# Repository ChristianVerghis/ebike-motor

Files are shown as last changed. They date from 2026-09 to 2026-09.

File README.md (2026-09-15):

# ebike-motor

**A from-scratch coreless dual-rotor axial-flux rear hub motor for a commuter e-bike, sized analytically and driven by a VESC.**

## What it is

A design-stage hardware project: a DIY coreless dual-rotor axial-flux (YASA-shaped, no iron) rear hub motor, direct drive, 135 mm dropout. Target ~350 W continuous / 750 W peak, ~40 Nm peak at the wheel, 26–27.5" wheel, 48 V, VESC FOC with regen. The stator is 12 epoxy-potted air coils between two 14-pole NdFeB rotors on steel back plates. A 1-D magnetic-circuit sizing script (`sim/sizing.py`) fixed the geometry and winding on 2026-09-01. Phases 0–3 run design, bench spin, wheel integration and a commute log.

Alongside the motor there is research into off-the-shelf conversion kits (`docs/conversion_kits.md`): which one to buy first as a rideable stepping stone and teardown benchmark, and which ones teach anything toward the build.

Everything in the repo is documentation, analysis and one script. Nothing has been machined or wound yet.

## Why I built it

I wanted to understand an electric machine by designing one end to end rather than buying a hub kit: magnet sizing and the air-gap flux budget, winding a coil count and gauge against copper loss and no-load speed, the axial pull between rotors, magnet temperature limits, epoxy glass transition, and how a low-inductance coreless machine behaves under sensorless FOC. Axial flux was chosen because a bicycle wheel is a large-diameter, low-RPM load, which is exactly the regime a pancake motor prefers, and a coreless stator is buildable on a bench with a 3D printer and no laminations.

## Status

As of 2026-09-15:

- Motor spec confirmed 2026-09-01 with `sim/sizing.py`: geometry, magnet size, winding, Kt/Kv, copper loss and rotor pull are pinned (PLAN.md Phase 0). FEMM cross-check still to do.
- Rotor back-plate DXF drawn (`cad/back_plate_3mm_steel.dxf`); no quote requested.
- Conversion-kit research done (`docs/conversion_kits.md`); a stepping-stone direct-drive hub purchase is proposed but undecided.
- BOM, sourcing and a master components list are priced. **No parts have been purchased.** Everything is design-stage.

## Design summary

Phase-1 targets. Numbers are from `sim/sizing.py` (1-D magnetic circuit with empirical leakage, good to roughly 10–15 %); FEMM is meant to refine them.

| Item | Value | Why |
|---|---|---|
| Topology | Dual-rotor, single coreless stator, no iron | No rotor-stator attraction, forgiving gaps, zero cogging, bench-buildable stator |
| Outer diameter | 240 mm | Torque scales with r²; fits inside 27.5" spokes |
| Poles / coils | 14 poles per rotor / 12 coils (LRK-style, wye) | Winding factor 0.933; ~29 Hz electrical at 250 rpm, no litz needed |
| Magnets | 28× N42 1"×1"×3/8" (25.4×25.4×9.5 mm), one per pole, radial at r 92–117 mm | 9.5 mm magnets across a 10 mm stator give ~0.49 T peak; 5 mm magnets only ~0.31 T |
| Rotor back plates | 3 mm mild steel, OD 240 / ID 130 | Flux return; stainless is non-magnetic |
| Stator | 10 mm epoxy/fibreglass potted disc, 2 mm air gap each side | Thinner stator raises gap flux; 2 mm gaps tolerate wobble |
| Winding | 30 turns × 2 strands 14 AWG per coil | Kt ≈ 0.48 Nm/A, ~460 rpm no-load at 42 V |
| Torque | ~29 Nm at 60 A, ~38 Nm at 80 A phase | VESC motor current max set to 80 A for launches |
| Copper loss | ~45 W at 8 Nm cruise, ~160 W at 15 Nm hill | Hill torque is minutes, not continuous; thermal cutback at 85 °C |
| Axial pull | ~0.8 kN between rotors | Carried rotor-to-rotor through OD bolts, not through the stator |
| Axle | 14 mm hub-motor replacement axle, Grin V7 14 mm torque arm | 12 mm hollow axles shear below 80 Nm at the arm |
| Controller | VESC 6-class FOC (Flipsky 75100 Pro candidate), 48 V 13S | Sensorless FOC and regen; low coreless inductance is the known gotcha |
| Core material | None in phase 1; laminated M270-35A segments in phase 2 | Ferrite saturates at ~0.45 T, rejected; rotors fixed so a cored stator drops in later |
| Magnet pattern | Plain alternating N-S; Halbach deferred | ~80 % of Halbach field, none of the orientation fiddliness |
| Mass | ~5 kg motor (1.3 kg magnets) | Coreless penalty, accepted for phase 1 |

## Layout

| Path | Contents |
|---|---|
| `PLAN.md` | Motor phases 0–3, milestones, timeline, risks |
| `GOALS.md` | Working checklist: Phase 0 design steps, bench motor, wheel and ride, north-star goals |
| `BOM.md` | Motor parts list, budget scenarios, what to 3D print and what not to |
| `SOURCING.md` | Priced supplier list per order (Order 0–3) |
| `build_log.md` | Dated log of decisions and research |
| `project.yml` | Project manifest (name, links, checklist sections) |
| `sim/sizing.py` | Analytical sizing: gap flux, Kt/Kv, copper loss, fill, rotor pull; prints a design sweep |
| `cad/` | `back_plate_3mm_steel.dxf` rotor back plate for laser/waterjet cutting, plus notes |
| `docs/design.html` | Motor diagrams: cross-section, coil/pole plan, exploded stack, bike placement, key numbers |
| `docs/roadmap.html` | Phase 0–3 timeline and where the torque number lands against commercial drives |
| `docs/conversion_kits.md` | Commercial kit research: what to buy first, what teaches anything |
| `docs/components.md` | Master buy list across the motor orders, bike side and tools |

The HTML pages are self-contained (inline SVG, no external assets); open them locally in a browser.

## Run the sizing script

Python 3, standard library only.

```sh
python3 sim/sizing.py
```

It prints a magnet-thickness / stator-thickness sweep of gap flux density, then candidate designs with Kt, peak torque, no-load rpm, phase resistance, continuous current, copper loss, current density, slot fill and rotor pull. Edit the candidate tuples at the bottom of the file to explore other windings.

## License

Code (`sim/`, `cad/`) is released under the MIT License, see [LICENSE](LICENSE). Documentation (`docs/`, this README and the other Markdown files) is licensed under Creative Commons Attribution 4.0 International, see [LICENSE-docs.md](LICENSE-docs.md).

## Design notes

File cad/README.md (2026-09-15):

# cad/

- `back_plate_3mm_steel.dxf` — rotor back plate, order **2×** in 3 mm (0.120") mild steel, A36/1008/HRPO. Units mm.
  OD 240, ID 130, 6× Ø5.5 on PCD 150 (M5 to carrier), 3× Ø3.1 jig-locating pins at r = 85 (inside the magnet ring).
  Magnets: 14× 1"×1"×3/8" (25.4×25.4×9.5 mm) per plate, radial, centred at r = 104.7 (r 92–117.4). Keep annulus 65–120 solid.
  Upload to SendCutSend / Fractory / local laser shop. Do NOT choose stainless (304/316 is non-magnetic).

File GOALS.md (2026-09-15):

# Goals & working checklist

Working checklist; tick items here. Sections are referenced by project.yml. Details: PLAN.md, SOURCING.md, docs/conversion_kits.md.

## Now — Phase 0 design (PLAN.md Phase 0)
- [ ] FEMM check of sim/sizing.py (Bpk ≈ 0.49 T, pull ≈ 0.8 kN)
- [ ] Decide on the stepping-stone direct-drive hub (Order 0, docs/conversion_kits.md) before Order 1
- [ ] Pick a donor bike: 135 mm QR open dropouts, 26/27.5", disc
- [ ] Order 1: magnets, VESC, wire, epoxy, torque arm
- [ ] SendCutSend quote on cad/back_plate_3mm_steel.dxf; Order 2 mechanical after the axle arrives
- [ ] CAD full assembly; export STLs for the jigs, coil former and stator mould

## Bench motor (PLAN.md Phase 1)
- [ ] Wind 12 coils on the printed former; pot the stator with 2 embedded NTCs
- [ ] Glue 28 magnets on the two back plates with the placement jig; check the pole pattern with a Hall probe
- [ ] Bench spin: 12-coil stator between two 14-pole rotors, > 200 W in, measure Kt / Kv / phase R
- [ ] Prony brake or trainer run: W in vs rpm × torque → efficiency map

## Wheel and ride (PLAN.md Phase 2–3)
- [ ] Lace the 27.5" rim on the final carriers; torque arm; 48 V 13S pack; VESC tune with regen
- [ ] Ride tests: flat speed, hill climb, thermal soak, regen feel

## North-star goals
- [ ] Bench spin of the custom motor
- [ ] Ride: hub laced, 48 V, 25 km/h flat, 350 W sustained < 100 °C
- [ ] Commute 4 weeks daily, regen, no thermal cutouts
- [ ] Phase 2: laminated segmented stator on the same rotors

Non-goals: beating a $150 Bafang on cost or weight.

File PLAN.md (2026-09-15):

# Plan

## Phase 0 — Design & simulate (weeks 1–4)
- [ ] **Proposed:** buy a direct-drive rear hub kit (Leaf 26" 1000 W, $210) and run it from the 75100 as a rideable stepping stone + teardown benchmark — see [docs/conversion_kits.md](docs/conversion_kits.md). Decide before Order 1
- [x] Pin key dimensions (sim/sizing.py, 2026-09-01): OD 240, 14× 1"×1"×3/8" N42 per rotor at r 92–117, 10 mm stator, 2 mm gaps, 12 coils × 30 t × 2×14 AWG
- [ ] FEMM 2D "unrolled" model at mean radius to confirm sizing.py (expect Bpk ≈ 0.49 T, B1 ≈ 0.46 T, pull ≈ 0.8 kN). Adjust turns ±3 if Kt is off
- [x] 12 coils / 14 poles, 30 turns × 2 strands 14 AWG → Kt ≈ 0.48 Nm/A, ~460 rpm no-load @ 42 V, J ≈ 5 A/mm² at 15 Nm
- [ ] Donor bike: 135 mm QR open dropouts, 26/27.5", disc, Al or steel (Trek FX/Marlin, Sirrus, Giant Escape, Kona Dew, Surly Cross-Check)
- [ ] Thermal budget: coil surface area, copper loss at 15 Nm continuous. Want ≤ 60 W copper loss
- [ ] Order 1: magnets, VESC, wire, epoxy, torque arm (see SOURCING.md)
- [ ] Get SendCutSend quote on cad/back_plate_3mm_steel.dxf; Order 2 mechanical
- [ ] CAD full assembly in FreeCAD/Fusion; export STLs for printed parts

## Phase 1 — Bench motor (weeks 5–12)
- [ ] Print coil-winding jig + coil former; wind 12 coils (count turns, measure R each; reject > 5% outliers)
- [ ] Print stator lay-up mould; lay coils, fibreglass, vacuum-bag/pot in epoxy with 2 embedded NTC thermistors
- [ ] Waterjet/laser 2× steel back plates; glue magnets with printed placement jig; check pole pattern with a Hall sensor
- [ ] Turn aluminium hub carriers; press bearings; assemble on 12 mm axle with shim spacers
- [ ] Spin by hand → check back-EMF waveform on scope (balanced 3-phase, no shorted turns)
- [ ] VESC motor detection; run to 400 rpm; measure Kt with a spring scale + lever arm
- [ ] Dyno-ish: prony brake / bike trainer, log W in vs rpm × torque → efficiency map

## Phase 2 — Wheel integration (weeks 13–18)
- [ ] Machine final spoke-flange carriers (36 h, 3-cross), lace 27.5" rim, true
- [ ] Hollow axle slot for phase + thermistor + hall wires; strain relief
- [ ] Torque arm, dropout fit, cassette clearance
- [ ] 48 V 13S battery pack (buy) + BMS, fuse, key switch, wiring loom
- [ ] VESC tune: current limits, thermal cutback at 90 °C, regen on brake-lever switch
- [ ] Ride tests: flat speed, hill climb, thermal soak, regen feel

## Phase 3 — Commute & iterate (weeks 19–26)
- [ ] 4-week daily-use log (Wh/km, peak coil temp, any noise)
- [ ] Decide: Halbach rotor upgrade and/or laminated cored stator (phase 2 design)

## Timeline
Realistic at evenings + weekends: **6 months** to a ridden commuter, 3 months to first bench spin.

## Risks
- N42 max operating temp 80 °C, coils 2 mm away → VESC thermal cutback at 85 °C, or buy N42H/SH
- Axial pull between rotors ≈ 0.8–1 kN (sizing.py) → shaft/bearing preload design; do not underbuild the hub carrier
- Coreless copper AC loss at 14-pole / 250 rpm ≈ 30 Hz electrical — low, fine. Litz not needed
- Coreless = low inductance; VESC FOC detection is finicky. Detect at half battery voltage, 5–10 A; lower observer gain if it desyncs. Bifilar 30 t helps
- Epoxy glass transition: use ≥ 120 °C Tg resin (e.g. West System 105/206 is NOT enough; use a high-temp laminating epoxy)
- Magnet handling: 28× 1"×1"×3/8" N42 blocks (38 lb pull each) will crush fingers. Print a spacer/handling jig

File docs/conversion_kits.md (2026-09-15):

# Conversion-kit research

Consolidated from design chats 2026-09-02 / 09-03. Question asked: should a bought kit come before the DIY axial-flux motor, and which kits actually teach anything toward the build? Prices USD as checked 2026-09-02.

## Verdict

**Yes, buy a kit first, but a bare direct-drive rear hub run from our own VESC, not a bolt-on booster.** Everything except the hub itself (battery, VESC, torque arm, throttle, e-brakes, wiring, donor bike) moves straight onto the DIY motor later. Proposed as **Phase 0** in PLAN.md (see below) — not yet confirmed, nothing bought.

## Category 1 — bolt-on speed boosters (rejected)

Chain/roller or friction drives with a sealed proprietary controller and a small battery. Teach cable routing and "what 450 W feels like", nothing about motors, FOC, hubs, or regen. Nothing carries forward.

| Product | Price | Notes |
|---|---|---|
| [Flipsky Z9](https://flipsky.net/products/flipsky-z9-bicycle-speed-booster-kit-for-increased-speed-with-48v-5-2ah-9ah-battery-copy) / [Z8](https://flipsky.net/products/z8) | $219–259 | 450 W outrunner, chain + roller on rear wheel, 48 V 5.2 or 9 Ah (≈250 Wh ≈ 12 km assist). [AliExpress spec](https://www.aliexpress.com/i/1005009445601751.html) |
| Rubbee X | ~$500–700 | Friction roller on rear tyre, swappable battery modules |
| Clip | ~$500 | Front-wheel friction drive clamped to fork |
| Skarper | ~$1,500 | Removable drive unit via a special rotor; closed system |
| Add-e, Velogical | $800–1,500 | European roller drives, well made, sealed |

Shared problems: slips in the wet, 250–500 W, proprietary controller, small battery, no reuse path.

## Category 2 — kits that teach something

Ranked by relevance to the axial-flux build.

### 1. Direct-drive rear hub + our own VESC — **recommended**

- [Leaf Bike 26" 48/52 V 1000 W rear motor wheel](https://www.leafbike.com/products/e-bike-hub-motor/26-inch-48v-52v-1000w-rear-electric-hub-motor-wheel-892.html) — **$210** (was $259). Gearless, 135 mm dropouts, Honeywell halls, double-wall rim, 12 ga spokes, freewheel or cassette, 7.3 kg. The Endless Sphere default for tinkering.
- Bench-only alternative: [HPC Bikes 1000 W 48 V front gearless wheel](https://hpcbikes.com/products/1000w-48v-front-gearless-hub-motor-wheel-26) — $80, front / 100 mm dropouts, so not a daily ride.
- Name-brand option: Bafang G062 direct-drive hub, documented [VESC retrofit thread](https://forums.electricbikereview.com/threads/bafang-g062-1000w-vesc-controller-retrofit.55915/). **Avoid geared hubs (e.g. Bafang G310)**: clutch kills regen and the gearbox hides the motor behaviour we want to study.
- Pair with parts already in SOURCING.md: Flipsky 75100 Pro V2.0 ($98), Grin V7 torque arm (~$58), 48 V 13S 12–15 Ah pack ($250–450), plus throttle / e-brake levers / XT90 / fuse / wire (~$60).

What it teaches: VESC detection, FOC tuning, hall vs sensorless, regen, thermal cutback, torque arms, dropout fit. Same architecture as our motor (radial instead of axial) → teardown benchmark for `sim/sizing.py`. Working commuter in a weekend.

Cost of this route ≈ **$600–900**, of which only the hub ($150–250) is not reused.

### 2. Tongsheng TSDZ2B with open-source firmware — teaches controller firmware

- [Electrify Bike TSDZ2B OSF kit](https://electrifybike.com/collections/tongsheng-motors) from $525 (standard 500 W kit $495; both sold out 2026-09-02). Also [Eco Cycles](https://www.eco-ebike.com/collections/tsdz2-open-source-firmware-osf-products), [Amazon](https://www.amazon.com/Tongsheng-Electric-Conversion-Firmware-Tricycle/dp/B0CZ64S2C3).
- Torque-sensing mid-drive, big OSF community. Learn flashing/tuning firmware, torque-sensor and FOC behaviour. Geared + radial, so little transfers to axial flux; only the battery is reused.

### 3. Bafang BBS02B — least learning, most reliable

- [Luna Cycle BBS02 750 W kit](https://lunacycle.com/bafang-bbs02-750w-middrive-kit/) — $470 without battery. Motor, 25 A controller, chainring, throttle, display. $19.95 programming cable tweaks assist curves; controller is closed. Pick only if a dependable commuter matters more than learning.

## Proposed Phase 0 sequence

1. Donor bike + Leaf direct-drive hub + battery + VESC + torque arm. Ride it.
2. Tear down and measure the hub (or buy the $80 HPC front hub as a bench specimen): magnet dims, turns, Kt, phase R → calibrate `sim/sizing.py`.
3. Build the coreless axial-flux motor on the bench with the VESC already tuned.
4. Swap wheels.

## Sources

[Flipsky e-bike collection](https://flipsky.net/collections/e-bike) · [Endless Sphere: VESC and Flipsky for e-bikes](https://endless-sphere.com/sphere/threads/vesc-and-flipsky-for-e-bikes.127684/) · [Bafang G062 VESC retrofit](https://forums.electricbikereview.com/threads/bafang-g062-1000w-vesc-controller-retrofit.55915/)

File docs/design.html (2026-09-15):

# ebike-motor — what we're aiming for

Coreless dual-rotor axial flux rear hub. 240 mm OD, 12 coils / 14 poles per rotor, 1"×1"×3/8" N42 magnets, 10 mm stator, 2 mm air gaps, 48 V VESC FOC. ~350 W cruise, ~38 Nm launch at 80 A.

## 1. Cross-section (through the axle)

Stator clamped to the fixed axle; both rotors ride on bearings and are bolted together through the OD so the magnet pull (~1 kN) is carried rotor-to-rotor, not through the stator. Flux crosses stator → opposite magnet → back plate → next pole → back across.

## 2. Plan view — coils & poles

12 slot / 14 pole (LRK-style). Coils wound identically; connect A–B–C round the ring, alternating direction per phase pair. Wye-connected to the VESC. Rotor opposite has the mirror pole pattern (N faces S across the stator).

## 3. Exploded stack

Assembly order. Shims on the axle between stator hub and bearings set each gap. Through-bolts at the OD join the two carriers.

## 4. Where it sits on the bike

Rear hub direct drive. At 25 km/h a 27.5" wheel turns ~230 rpm — the low-RPM/high-torque regime an axial flux pancake likes, no gearbox. Regen braking via VESC on the brake-lever switch.

## 5. Key numbers (phase 1 targets)

Item | Target | Why
Outer diameter | 240 mm | Torque ∝ r²; fits inside 27.5" spokes
Gap flux density | 0.49 T pk / 0.46 T fund. | 9.5 mm N42 both sides, 10 mm stator + 2×2 mm gaps (sizing.py)
Kt / Kv | 0.48 Nm/A · ~11 rpm/V | 30 t × 2×14 AWG; ~460 rpm no-load @ 42 V
Peak torque | 29 Nm @ 60 A · ~38 Nm @ 80 A | Set VESC motor max 80 A
Cruise / hill | 8 Nm ≈ 45 W Cu · 15 Nm ≈ 160 W Cu | Hill torque is minutes not hours; cutback 85 °C
Mass (motor) | ~5 kg (1.3 kg magnets) | Coreless penalty; accepted for phase 1
Electrical freq @ 250 rpm | ~29 Hz | Low: solid 1 mm wire fine, no litz

Phase 2 swaps in a laminated M270-35A segmented stator on the same rotors for ~1.8× torque density; ferrite rejected (saturates ~0.45 T).

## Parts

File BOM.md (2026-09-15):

# Bill of materials & budget

Prices are rough USD, mid-2026, hobby quantities. Ranges cover cheap-AliExpress vs. reputable-supplier.

## A. Motor — magnetics & winding

| # | Part | Spec | Qty | Est. | Notes |
|---|---|---|---|---|---|
| 1 | NdFeB block magnets | **N42 1"×1"×3/8"** (25.4×25.4×9.5 mm), Ni-Cu-Ni | 28 (+4 spare) | **$171** @ $5.35 | Applied Magnets. 1 per pole, radial. 54 % pole coverage at mean radius. One batch. (Alt: 3× 30×10×10 metric/pole — not stocked anywhere found) |
| 2 | Steel back plates | 3 mm mild steel, Ø240 / Ø130 ring, cad/back_plate_3mm_steel.dxf | 2 | $30–60 | Laser/waterjet. NOT stainless |
| 3 | Magnet wire | **14 AWG** (1.63 mm) enamelled Cu, 200 °C, **5 lb spool** | 1 | ~$90–110 | 12 coils × 30 turns × **2 strands in hand** ≈ 110 m / 360 ft; 14 AWG ≈ 80 ft/lb |
| 4 | Laminating epoxy, high-Tg | e.g. Sicomin SR1710 or MGS L285 w/ slow hardener | 1 kg kit | $60–90 | Tg ≥ 120 °C. Standard West System will soften |
| 5 | Fibreglass cloth | 200 gsm plain weave, 1 m² | 1 | $15 | Stator disc reinforcement |
| 6 | Kapton tape, fibreglass sleeving, PET braid | — | — | $20 | Coil-to-coil insulation, phase leads |
| 7 | NTC thermistors 10k | glass-bead | 3 | $6 | 2 embedded in coils, 1 spare |
| 8 | Magnet adhesive | Loctite 326 + activator, or 3M DP460 | 1 | $25 | Structural, ≥ 120 °C |
| | **Subtotal A** | | | **$420–520** | |

## B. Motor — mechanical

| # | Part | Spec | Qty | Est. | Notes |
|---|---|---|---|---|---|
| 9 | Axle | **14 mm hub-motor replacement axle**, M14×1.5, 10 mm flats, wire slot (Ebike Solution UK £25 / Amazon–AliExpress $20–30) | 1 | $25–35 | Buy first; bearings sized to its centre diameter (usually 17 or 20 mm → 6003 / 6004). 12 mm hollow axles shear < 80 Nm at the torque arm |
| 10 | Bearings | 6003-2RS (17×35×10) or 6004-2RS (20×42×12) — match axle | 4 (+2) | $15–25 | Order after axle arrives |
| 11 | Aluminium rotor/spoke carriers | 6061, Ø250 × 20 mm blanks | 2 | $60–120 | Machined (lathe) or sent to a CNC shop (~$150–250 if outsourced) |
| 12 | Stator hub | 6061 Ø80 × 40 mm | 1 | $15 | Clamps stator disc to axle |
| 13 | Shim spacers | 12 mm ID, 0.1 / 0.2 / 0.5 mm | set | $12 | Sets the two air gaps |
| 14 | Fasteners | M4/M5 stainless cap screws, Nyloc, thread-locker | — | $25 | |
| 15 | Torque arm | **Grin V7 Regen, 14 mm variant** | 1 | ~$58 | Mandatory for regen; clamps axle flats |
| 16 | Spokes + nipples | 13G/14G stainless, cut to length | 36 + spares | $40 | Length depends on flange dims |
| 17 | Rim | 27.5" double-wall, 36 h | 1 | $40–80 | Or re-use the bike's rim |
| | **Subtotal B** | | | **$250–400** | |

## C. Electrical

| # | Part | Spec | Qty | Est. | Notes |
|---|---|---|---|---|---|
| 18 | Controller | VESC 6-class FOC (Flipsky 75100 / Trampa VESC 6 MkVI / MakerX) | 1 | $90–250 | Sensorless FOC + regen; ≥ 60 A |
| 19 | Battery | 48 V 13S 12–15 Ah Li-ion, downtube or rack, with BMS | 1 | $250–450 | Buy, don't build, for a commuter |
| 20 | Throttle + brake-cutoff levers | Hall thumb throttle, e-brake levers | 1 set | $25–40 | |
| 21 | Display / VESC Bluetooth module | for tuning & data | 1 | $20–35 | |
| 22 | Connectors, fuse, key switch, silicone wire | XT90-S, 12 AWG, 40 A fuse | — | $40 | |
| 23 | Hall sensors (optional) | SS41 / 44E ×3 | 3 | $5 | Sensorless FOC usually fine; add if start-up stutters |
| | **Subtotal C** | | | **$430–820** | |

## D. Tools & consumables (if you don't own them)

| # | Item | Est. | Notes |
|---|---|---|---|
| 24 | 3D printer filament (PETG / ASA / PA-CF) | $40 | jigs, formers, moulds, covers |
| 25 | Vacuum bag + pump (or brake bleeder) | $40–80 | For stator lay-up. Optional but improves fill |
| 26 | Digital scale, calipers, multimeter, clamp meter | $60 | |
| 27 | Cheap oscilloscope (or VESC tool) | $50–100 | Back-EMF check |
| 28 | Spring scale / luggage scale | $15 | Kt measurement |
| 29 | Lathe time / CNC outsourcing | $0–250 | Biggest variable |
| | **Subtotal D** | **$200–600** | |

## Budget summary

| Scenario | Total |
|---|---|
| Lean (own tools, AliExpress, machine own carriers, reuse rim) | **~$1,100** |
| Typical | **~$1,600** |
| Comfortable (Trampa VESC, quality battery, outsourced CNC) | **~$2,000+** |

Roughly half is the battery + controller you'd buy for *any* e-bike. Motor-specific spend is ~$500–800.

## What to 3D print

Print **everything that doesn't carry magnetic or structural load**. Print nothing that sits in the flux path or holds the magnets against the 1–2 kN axial pull.

### Print these (PETG or ASA; PA-CF where noted)
- **Coil winding former** — trapezoidal bobbin matching coil pitch; two-part with a bolt so the finished coil pops off
- **Coil bundling jig** — 12-pocket ring that holds finished coils at exact angular pitch during lay-up
- **Stator lay-up mould** — two-part disc mould, 2–3 mm oversize; release wax; epoxy poured inside. Print smooth (0.12 mm layers) or sand
- **Magnet placement jig** — ring with 14 pockets that locates each magnet on the steel plate while adhesive cures. Print in **PA-CF or PETG ≥ 4 walls**; N-S handling spacer combs too
- **Gap-setting gauges** — 2.0 mm comb feelers for checking the gap all round after assembly
- **Rotor covers / dust shields** — thin ASA discs, non-structural
- **Wire exit strain-relief / axle grommet** — TPU
- **Hall sensor carrier** (if used) — small PCB holder at the stator OD
- **VESC enclosure, battery-cable clips, controller mount**
- **Dyno arm and spring-scale bracket** for Kt tests
- **Prototype rotor carriers** — printed carriers are for **dry-fit / geometry check only, without magnets on both rotors**. Full-coverage rotors pull ~3 kN; do not spin on printed carriers

### Do NOT print
- Rotor back plates (must be steel — flux return path)
- Final rotor/spoke carriers (spoke tension + axial magnetic pull + braking load)
- Axle, stator hub clamp, torque arm
- Anything within 3 mm of a coil at continuous ≥ 90 °C without confirming material Tg (PETG softens ~80 °C; ASA ~100 °C; PA-CF ~150 °C)

### Phase-2 note
If you go to laminated cores later, print the **lamination stacking fixture** and **segment bobbins** (PA-CF). The cores themselves stay steel.

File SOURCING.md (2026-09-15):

# Sourcing — first order (Phase 0 long-lead parts)

Prices checked 2026-09-01, USD, US suppliers unless noted. Buy these now; everything else waits for FEMM results.

## Order 1 — magnetics & controller (≈ $450–520) — **confirmed spec 2026-09-01, sim/sizing.py**

| Part | Supplier | Spec / SKU | Qty | Price | Status |
|---|---|---|---|---|---|
| N42 block 1"×1"×3/8" | [Applied Magnets](https://appliedmagnets.com/n42-neodymium-magnets-1-in-x-1-in-x-3-8-in-rare-earth-block/) (= Magnet4Less) | 25.4×25.4×9.5 mm, Ni-Cu-Ni, ~38 lb pull | **32** (28 + 4 spare), one order | $5.35 ea → **$171** | ☐ |
| VESC controller | [Flipsky 75100 Pro V2.0](https://flipsky.net/products/flipsky-75100-pro-v2-0-with-aluminum-pcb-based-on-vesc-for-electric-skateboard-electric-scooter-ebike-speed-controller) | 14–84 V, 100 A cont / 150 A pk, HALL port | 1 | **$98** (button) / $104 (key) | ☐ |
| Magnet wire **14 AWG** 200 °C | [Remington Industries](https://www.remingtonindustries.com/magnet-wire/) polyamide-imide | **5 lb spool (~400 ft)** | 1 | ~$90–110 (confirm on site) | ☐ |
| High-temp laminating epoxy | [Fibre Glast System 3000](https://www.fibreglast.com/products/high-temp-epoxy-resin-3000) quart | 309 °F service, post-cure 150 °C | 1 | **$137** | ☐ |
| 14 mm hub-motor axle | [Ebike Solution UK](https://ebikesolution.co.uk/products/m14-ebike-axle-for-hub-motors-kits-for-135mm-replacement) £25, or Amazon/AliExpress "hub motor axle 14mm 135mm" | M14×1.5, flats, wire slot | 1 | $25–35 | ☐ |
| Torque arm | [Grin V7 Regen — **14 mm** variant](https://ebikes.ca/shop/electric-bicycle-parts/torque-arms.html) | clamps flats | 1 | ~$58 | ☐ |

## Order 2 — mechanical (≈ $150–250, after the axle arrives)

| Part | Supplier | Spec | Qty | Price | Status |
|---|---|---|---|---|---|
| Steel back plates | [SendCutSend](https://sendcutsend.com/pricing/) — upload `cad/back_plate_3mm_steel.dxf` | 3 mm A36/1008 mild steel | 2 | est. $25–45 (min order $29) | ☐ |
| Bearings | match axle centre Ø: 6003-2RS (17 mm) or 6004-2RS (20 mm) | ABEC-3+ | 4 (+2) | $15–25 | ☐ |
| 6061 round blanks | OnlineMetals / local | Ø250×20 mm ×2, Ø80×40 ×1 | 3 | $60–120 | ☐ |
| Shim set | McMaster / Amazon | ID to match axle, 0.1 / 0.2 / 0.5 mm | 1 set | $12 | ☐ |
| Magnet adhesive | Loctite 326 + 7649 activator, or 3M DP460 | | 1 | $25 | ☐ |
| Fibreglass 200 gsm, Kapton, NTC 10k ×3, M5 hardware | Amazon | | | $50 | ☐ |

## Order 3 — bike side (Phase 2, don't buy yet)
48 V 13S battery ($250–450), throttle + e-brake levers, XT90-S, 40 A fuse, 27.5" 36 h rim + spokes.

## Filament
1 kg PETG (jigs), 1 kg ASA or PA-CF (magnet jig, mould). ~$40.

## Notes
- **Buy all magnets from one lot** — Br variance between lots shows up as torque ripple.
- **Why 1"×1"×3/8" and not 30×10×5:** sim/sizing.py — 5 mm magnets across a 15 mm stator give ~0.31 T peak; 9.5 mm magnets across a 10 mm stator give ~0.49 T. 1"×1"×1/2" ($5.89) adds < 1 % — gap-limited, not worth the 430 g. 30×10×10 metric isn't stocked by any supplier found.
- **Peak torque is ~30 Nm at 60 A phase; set VESC motor current max 80 A for ~40 Nm launches.** Cruise (8 Nm, 25 km/h flat) ≈ 45 W copper loss; 15 Nm hill ≈ 150–170 W — minutes, not continuous.
- **Post-cure**: System 3000 wants ~150 °C. Demould first or print the mould in ASA/PA-CF. Never post-cure with magnets present (N42 irreversibly loses field > 80 °C).
- **Axle is 14 mm, not 12** (12 mm hollow axles shear under 80 Nm at the arm per Grin's testing). Grin V7 comes in a 14 mm variant.
- **Low inductance**: coreless = tens of µH. Expect to raise VESC switching frequency and re-run detection; FOC current ripple is the known coreless gotcha.
- Flipsky 75100 has no dedicated motor-temp port; wire the coil NTC to the VESC's ADC/temp input (documented on VESC forum) or read it via a $5 module. Trampa VESC 6 MkVI ($250+) is the upgrade path if the Flipsky's FOC is noisy at low rpm.
- Magnet Expert ships from the UK; for US delivery K&J or Applied Magnets are faster. Verify exact 30×10×5 or adjust the placement jig to whatever size you get — the design tolerates 25–32 mm × 8–12 mm × 4–6 mm with a re-run of FEMM.
- The 2.5 lb wire spool is comfortably enough for 12 coils × 45 turns plus rewinds.

## Order 0 (proposed, undecided) — stepping-stone hub kit, see docs/conversion_kits.md

| Part | Supplier | Spec | Qty | Price | Status |
|---|---|---|---|---|---|
| Direct-drive rear hub in 26" wheel, motor only | [Leaf Bike 48/52 V 1000 W](https://www.leafbike.com/products/e-bike-hub-motor/26-inch-48v-52v-1000w-rear-electric-hub-motor-wheel-892.html) | gearless, 135 mm, halls, 7.3 kg | 1 | $210 | ☐ |
| Bench teardown specimen (optional) | [HPC 1000 W front gearless wheel](https://hpcbikes.com/products/1000w-48v-front-gearless-hub-motor-wheel-26) | 100 mm front | 1 | $80 | ☐ |
| Throttle, e-brake levers, XT90, fuse, wire | Amazon / ebikes.ca | | | ~$60 | ☐ |

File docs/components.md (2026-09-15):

# Components — master buy list

One place for everything we are likely to buy for the axial-flux motor and the bike around it. Prices are the ones checked when each line was researched (USD unless noted). Status: ☐ not ordered · ◐ ordered · ☑ in hand. Detailed supplier notes stay in [SOURCING.md](../SOURCING.md); this is the reference view.

## A. Axial-flux motor — Order 1 magnetics & controller (~$450–520)

| Part | Candidate product | Spec | Qty | Est. | Status |
|---|---|---|---|---|---|
| Magnets | Applied Magnets N42 block 1"×1"×3/8" | 25.4×25.4×9.5 mm Ni-Cu-Ni | 32 | $171 | ☐ |
| Controller | **Flipsky 75100 Pro V2.0** (VESC) | 14–84 V, 100 A cont, hall port | 1 | $98 | ☐ |
| Magnet wire | Remington 14 AWG 200 °C, 5 lb spool | polyamide-imide | 1 | $90–110 | ☐ |
| High-temp epoxy | Fibre Glast System 3000, quart | 150 °C post-cure | 1 | $137 | ☐ |
| Hub axle | M14 hub-motor axle, 135 mm | flats + wire slot | 1 | $25–35 | ☐ |
| Torque arm | Grin V7 regen, 14 mm | | 1 | $58 | ☐ |

## B. Axial-flux motor — Order 2 mechanical (~$150–250, after the axle arrives)

| Part | Candidate | Spec | Qty | Est. | Status |
|---|---|---|---|---|---|
| Steel back plates | SendCutSend, `cad/back_plate_3mm_steel.dxf` | 3 mm mild steel | 2 | $25–45 | ☐ |
| Bearings | 6003-2RS or 6004-2RS to match axle centre | ABEC-3+ | 4 (+2) | $15–25 | ☐ |
| 6061 round blanks | OnlineMetals | Ø250×20 ×2, Ø80×40 ×1 | 3 | $60–120 | ☐ |
| Shim set, magnet adhesive, fibreglass 200 gsm, Kapton, 3× NTC 10k, M5 hardware | McMaster / Amazon / Loctite 326 | | | ~$90 | ☐ |

## C. Bike side — Order 3 (~$400–700)

| Part | Candidate | Spec | Qty | Est. | Status |
|---|---|---|---|---|---|
| Battery | 48 V 13S 12–15 Ah pack with BMS (Hailong) | UL-listed cells preferred | 1 | $250–450 | ☐ |
| Donor bike | used hybrid/MTB, 135 mm QR, disc, 26/27.5" (Trek FX/Marlin, Sirrus, Giant Escape, Kona Dew) | | 1 | $150–400 | ☐ |
| Direct-drive learning hub (optional Phase 0) | Leaf 26" 1000 W rear, motor only | | 1 | $210 | ☐ undecided |
| Teardown specimen (optional) | HPC 1000 W 48 V front gearless wheel | magnet grade/count, lamination stack → calibrate sim/sizing.py | 1 | $80 | ☐ |
| Throttle, e-brake levers, fuse, key switch, wiring loom | Amazon / ebikes.ca | | | $60 | ☐ |

## D. Tools & measurement (~$250)

| Tool | Candidate | Why | Est. | Status |
|---|---|---|---|---|
| Digital calipers with depth rod + feeler gauges | Mitutoyo-clone 150 mm, 0.05–1 mm feelers | air gaps, magnet placement, shim stack | $35 | ☐ |
| Luggage scale + 0.5 m lever arm | 50 kg hanging scale | wheel torque = force × arm → Kt | $15 | ☐ |
| IR thermometer / K-type probe | | coil and shell temperature | $25 | ☐ |
| Wheel truing stand | Park TS-8 class | lacing, rotor runout | $60–80 | ☐ |
| Clamp meter or VESC logging | VESC Tool on phone | phase current → Kt | $0 | ☑ (VESC) |
| Hall-effect probe or phone magnetometer | | rotor pole check | $0–20 | ☐ |
| Crimpers for XT/JST, heat gun | | | $40 | ☐ |
| Sound level meter app | phone | dB at 1 m | $0 | ☑ |

## Totals

| Block | Est. |
|---|---|
| A Axial magnetics + VESC (Order 1) | ~$450–520 |
| B Axial mechanical (Order 2) | ~$150–250 |
| C Bike side (Order 3) | ~$400–700 (+ donor bike) |
| D Tools | ~$250 |
| **All of it** | **~$1,250–1,750** (+ donor bike) |

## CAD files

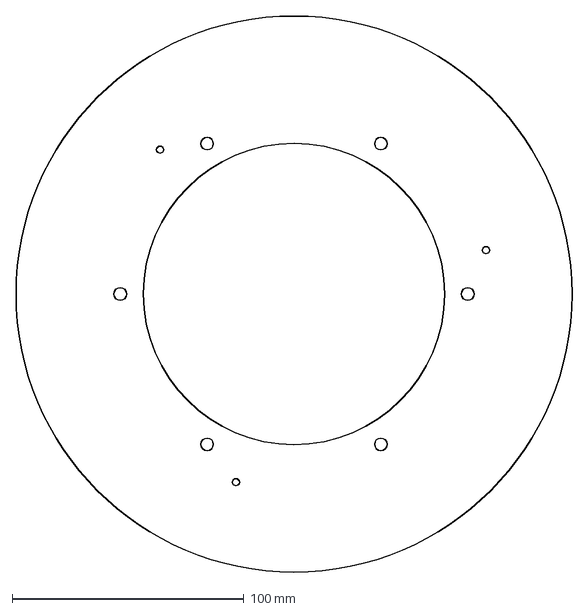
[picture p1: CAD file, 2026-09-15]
cad/back_plate_3mm_steel.dxf
240.0 x 240.0 mm

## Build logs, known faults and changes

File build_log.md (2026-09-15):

# ebike-motor build log

**Update 2026-09-01**: repo scaffolded.

**2026-09-01** — Design converged over a chat session: coreless dual-rotor axial flux (YASA-shaped, no iron) rear hub, plain N-S magnets on steel back plates (Halbach deferred), 12 coil / 14 pole, 240 mm OD, 2 mm gaps, VESC FOC. Ferrite cores rejected (saturate ~0.45 T); laminated M270-35A segments are the phase-2 stator on the same rotors. Wrote PLAN.md (4 phases, ~6 months), BOM.md (~$950–2,000, motor-specific ~$500–800, 3D-print list), docs/design.html (cross-section, coil/pole plan, exploded stack, bike placement).

**2026-09-01 (later)** — Repo created and pushed (ChristianVerghis/ebike-motor). Priced Order 1: Flipsky 75100 Pro V2 $98, Remington 18 AWG 200 °C wire, Fibre Glast System 3000 epoxy $137/qt, Grin V7 regen torque arm $58, N42 30×10×5 magnets ~$2–3.50 ea. Wrote SOURCING.md and cad/back_plate_3mm_steel.dxf (OD 240 / ID 130 / 6×M5 PCD 150) for a SendCutSend quote.

**2026-09-01 (compat review)** — Parts sourced. Cross-check found: (1) 14 single 10 mm magnets/rotor = ~20 % pole coverage → 3 across per pole, 84 + spares; (2) 5 mm magnets over ~19 mm total magnetic gap ≈ 0.4–0.45 T, not 0.6 → FEMM gate: 10 mm stator or stacked magnets; (3) rotor pull ~3 kN not 1–2; (4) N42 Tmax 80 °C → cutback 85 °C / N42H; (5) 2 strands 18 AWG in hand; (6) coreless low inductance vs VESC FOC; (7) System 3000 post-cure vs PETG mould. Budget now ~$1,100–2,200. Donor bike criteria added.

**2026-09-01 (spec confirmed)** — Wrote sim/sizing.py (1-D magnetic circuit + leakage + winding/thermal). Result: 30×10×5 magnets are gap-limited (0.31 T pk with 15 mm stator) → switched to Applied Magnets 1"×1"×3/8" N42 ($5.35, 28 pcs), one per pole radial at r 92–117, stator thinned to 10 mm → 0.49 T pk. 1/2" thick adds <1 %. Winding 30 t × 2×14 AWG (5 lb spool): Kt 0.48, 460 rpm no-load, cruise 45 W Cu, 15 Nm hill 160 W. Peak ~38 Nm at 80 A. Pull ~0.8 kN. Axle → 14 mm hub-motor replacement + Grin V7 14 mm (12 mm hollow shears <80 Nm). Bearings deferred until axle Ø known. DXF jig pins moved to r=85.

## 2026-09-07
- Consolidated conversion-kit research (Flipsky Z8/Z9 rejected; Leaf direct-drive hub + own VESC recommended as Phase 0; TSDZ2 OSF and BBS02 as alternatives) into docs/conversion_kits.md. Phase 0 kit purchase still undecided.

## 2026-09-15
- docs/components.md: master buy list across the motor orders, bike side and tools, ~$1,250–1,750 plus the donor bike.
